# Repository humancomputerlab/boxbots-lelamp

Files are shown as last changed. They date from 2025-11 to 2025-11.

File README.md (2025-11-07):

# LeLamp

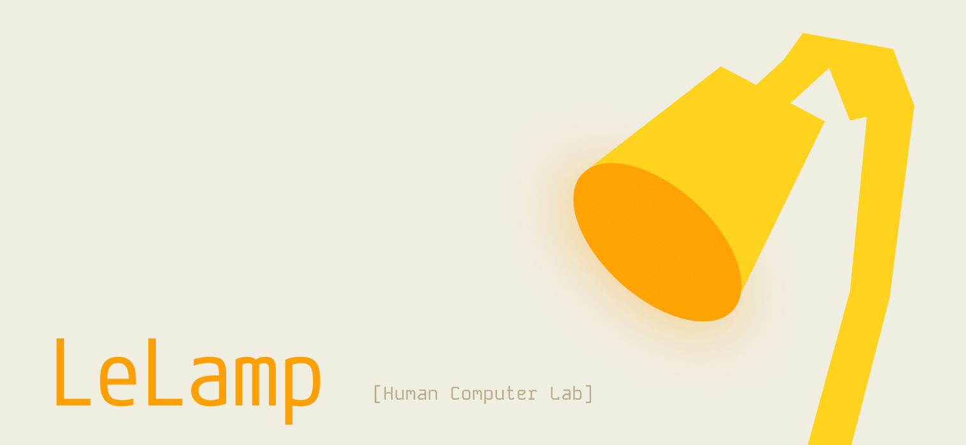
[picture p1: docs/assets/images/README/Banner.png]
LeLamp Banner


An open source robot lamp based on [Apple's Elegnt](https://machinelearning.apple.com/research/elegnt-expressive-functional-movement), made by [Human Computer Lab](https://www.humancomputerlab.com/)

## Overview

LeLamp is an expressive robot lamp featuring:

- 🎭 **5-axis articulated movement** with servo motors
- 📸 **Computer vision** via Pi Camera
- 🎤 **Audio interaction** with microphone and speaker
- 💡 **LED expressions** with 24 programmable LEDs
- 🎮 **Record & replay** custom movements

## Build Guide

**Start here:** [Prerequisites & Planning](./docs/0.%20Prerequisites.md)

### Complete Build Process

1. [📋 Prerequisites & Planning](./docs/0.%20Prerequisites.md) - Skills, tools, and BOM
2. [🔧 Components & 3D Parts](./docs/1.%203D%20Print.md) - Components and 3D Printed Models
3. [🎯 Lamp Assembly](./docs/3.%20LeLamp%20Assembly.md) - Mechanical and electrical assembly
4. [🏗️ Lamp Setup](./docs/4.%20LeLamp%20Setup.md) - Runtime Setup
5. [🎮 Lamp Control](./docs/5.%20LeLamp%20Control.md) - Controlling LeLamp
6. [🔍 Common Issues](./docs/6.%20Common%20Issues.md) - Common issues and solutions

### Quick Reference

- **Bill of Materials**: [Complete component list with suppliers](./docs/0.%20Prerequisites.md#bill-of-materials)
- **3D Print Files**: Available in `/3D/` directory ([OnShape CAD](https://cad.onshape.com/documents/16c9706360b5ad34f9c8db49/w/2edfa54c83253c120fbc9e58/e/a7196194821d9cfe2842a44a))
- **Order the Kit**: [Register interest here](https://docs.google.com/forms/d/e/1FAIpQLSfOXO2q_I2LKqYE0LoPN8VtrpKWrvJ1OkRAiS1iBFML1eqoGw/viewform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)
- **Software Control**: [LeLamp Runtime Repository](https://github.com/humancomputerlab/lelamp_runtime)

## Project Status

⚠️ **Early Development** - This project is actively being developed. We published our progress early to encourage community feedback and iteration.

## Community & Support

### Getting Help

- **Start here**: [Troubleshooting Guide](./docs/6.%20Troubleshooting.md) for common issues
- **Discord**: [Join our community](https://discord.gg/727JXBt8Zt) for real-time help and discussions
- **GitHub Issues**: [Report bugs or ask questions](https://github.com/humancomputerlab/le_lamp/issues)

### Contributing

We welcome contributions:

- 🐛 Bug reports and fixes
- 📖 Documentation improvements
- 🔧 Design enhancements
- 🌍 Regional supplier information
- 📸 Build photos and videos

Please check existing issues before creating new ones.

## Maintainers
Maintained by [Human Computer Lab](https://www.humancomputerlab.com).

## Acknowledgments & Sponsors
See [CONTRIBUTORS.md](./CONTRIBUTORS.md) for contributors and their roles.  
See [SPONSORS.md](./SPONSORS.md) for sponsor thanks and how to support the project.

## License

This project is licensed under the GNU General Public License v3.0 - see the [LICENSE](LICENSE) file for details.

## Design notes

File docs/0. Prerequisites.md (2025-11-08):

# Prerequisites for Building LeLamp

Before starting your LeLamp build, ensure you have the necessary skills, tools, and time to complete this project successfully.

## Skill Level Requirements

**Intermediate to Advanced** - This project requires:

- **Electronics experience**: Soldering, basic circuit understanding, component identification
- **3D printing knowledge**: Printer operation, material selection, post-processing
- **Software comfort**: Command line usage, SSH, basic Linux administration
- **Mechanical assembly**: Precision work with small components, heat inserts, servo mounting

**Estimated build time**: 1-2 hours (assuming prints are complete

## Required Tools

### Electronics Tools

- Soldering iron (temperature controlled, 15-25W)
- Solder (60/40 rosin core, 0.6-0.8mm)
- Wire strippers
- Small screwdrivers (Phillips #0, #1, flathead 2-3mm)
- Multimeter for continuity testing

### Mechanical Tools

- Heat insert soldering iron tip OR dedicated heat insert tool
- M2, M2.5 and M3 Allen keys/hex drivers
- Small pliers (needle nose)
- Wire cutters/flush cutters
- Digital calipers (for verification)

## Safety Warnings

⚠️ **ELECTRICAL SAFETY**

- Always disconnect power when making connections
- Use proper ESD precautions when handling Pi and servo driver
- Main power supply is 5V - verify correct voltage before connection
- Double-check polarity before powering on

⚠️ **MECHANICAL SAFETY**

- Heat inserts reach 200°C+ - use appropriate tools
- Servo horns under tension can snap - wear eye protection
- Small parts present choking hazard

**Total estimated cost (United States): $310.64 USD**

## Required External Resources

Before starting, ensure you have access to:

- **3D Printer** or printing service
- **Computer** for Pi setup and servo configuration
- **WiFi network** for Pi connectivity
- **LeLamp Runtime Repository**: https://github.com/humancomputerlab/boxbots_lelampruntime

## Time Planning

### Phase 1: Preparation (15-30 minutes)

- Download and review all documentation
- Source all components

### Phase 2: Electronics Prep (30-45 minutes)

- Test all components individually
- Solder headers and connectors
- Set up Raspberry Pi OS
- Configure servo IDs

### Phase 3: Assembly (30 min - 1 hour)

- Install heat inserts
- Mount servos in 3D printed parts
- Route wiring through body
- Assemble head components
- Final integration and testing

## Pre-Build Checklist

- [ ] All components sourced and verified working
- [ ] 3D parts printed and post-processed
- [ ] Tools and workspace prepared
- [ ] Software downloaded and accounts created
- [ ] Safety equipment ready
- [ ] Adequate time allocated (don't rush!)

## Getting Help

If you encounter issues:

- **Discord Community**: https://discord.gg/RJeRbR9sdP
- **GitHub Issues**: Report bugs and ask questions
- **Documentation**: Always check troubleshooting section first

---

**Next Step**: [1. 3D Print LeLamp](./1.%20Components%20Overview.md)

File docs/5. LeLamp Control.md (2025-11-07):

# Lamp Control

**⏱️ Estimated time:** 30 minutes  
**🔧 Required tools:** Computer with LeLamp runtime  
**📦 Required:** Fully assembled LeLamp with working head and body

For complete lamp control documentation, refer to the [**LeLamp Runtime's GitHub**](https://github.com/humancomputerlab/lelamp_runtime).

To follow this tutorial, ssh into your LeLamp and cd into `lelamp_runtime`. This was covered in the previous tutorial.

In commands below, remember to replace the name after `--id` to be your lamp name that you have used in previous section.

### Servo

Connect Pi to the servo driver through the USB port, then run the following to find which port the servo is connected to:

```bash
uv run lerobot-find-port
```

You need to unplug your USB during this process to find which port the servo is connected to. Most likely it is `/dev/ttyACM0`.

## Calibration

Before recording and replaying movements on the lamp, you need to calibrate:

```bash
sudo uv run -m lelamp.calibrate --id your_lamp_name --port your_port
```

The calibration script will run calibration twice, once for the lamp as a follower and once for the lamp as the leader. Follow the step outlined inside the CLI.

The script will mention you to put LeLamp into its zero position. The zero position is can be view in 3D [here](https://cad.onshape.com/documents/16c9706360b5ad34f9c8db49/w/2edfa54c83253c120fbc9e58/e/9bd935d578a9cbc77b5d66b3).

After putting LeLamp into its zero position, rotate each joint fully except for the lamp base motor (first motor on the base) or the lamp head motor (second motor from lamp head). **⚠️ Important: Do not fully rotate the lamp base or lamp head during calibration — this applies specifically to the two yaw servos. When setting them to their zero position, only rotate each servo about 90° clockwise and 90° counterclockwise from the center position. Rotating beyond this range may damage the servos or misalign the calibration.**

Then run the following command to check whether the servos are available and working:

```bash
uv run -m lelamp.test.test_motors --id your_lamp_name --port port_your_servo_driver_is_connected_to
```

## Record and replay movements

To record movement, run the following command in runtime:

```bash
sudo uv run -m lelamp.record --id your_lamp_name --port your_port --name rotation
```

While recording movement, you can end and save the recording by holding `CTRL + C`.

To replay movement, run the following command in runtime:

```bash
sudo uv run -m lelamp.replay --id your_lamp_name --port your_port --name rotation
```

To list all recorded movements, run the following command in runtime:

```bash
sudo uv run -m lelamp.list_recordings --id your_lamp_name
```

## Final System Testing

After completing your LeLamp build, perform these final tests:

### Full System Integration Test

```bash
# Test all servo movements
sudo uv run -m lelamp.test.test_motors --id your_lamp_name --port your_port

# Test head components
sudo uv run -m lelamp.test.test_rgb     # LED ring
uv run -m lelamp.test.test_audio        # Audio I/O
libcamera-hello --timeout 2000         # Camera
```

### Record Your First Movement

1. **Position LeLamp** in a safe working area with full range of motion
2. **Record a simple movement** to test the system
3. **Replay the movement** to verify accuracy
4. **Save successful recordings** for future use

## Congratulations! 🎉

You have successfully built your LeLamp! Your robot lamp should now be capable of:

- ✅ Expressive movement through 5 degrees of freedom
- ✅ Visual interaction via camera
- ✅ Audio input/output for voice interaction
- ✅ Programmable LED expressions
- ✅ Recording and replaying custom movements

## Next Steps

- **Explore the runtime**: Check out advanced features in the [LeLamp Runtime repository](https://github.com/humancomputerlab/lelamp_runtime)
- **Join the community**: Share your build on [Discord](https://discord.gg/4hmNW3Ep)
- **Contribute back**: Help improve documentation or share build photos
- **Report issues**: Use [GitHub Issues](https://github.com/humancomputerlab/le_lamp/issues) for bugs or suggestions

---

**Previous**: [LeLamp Setup](./4.%20LeLamp%20Setup.md) | **Troubleshooting**: [Common Issues](./6.%20Common%20Issues.md)

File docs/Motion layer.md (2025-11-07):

# Lelamp Studio

https://github.com/humancomputerlab/lelamp-studio

A web-based visual interface for animating and controlling the Lelamp robot. This React application provides a node-based graph editor to create robot animations, visualize URDF models in 3D, and export motion sequences for the robot lab.

## What It Is

The Lelamp Interface is a browser-based tool for:
- **3D Robot Visualization**: Load and view URDF robot models with interactive joint manipulation
- **Node-Based Animation Editor**: Create animation sequences using a visual graph of joint poses and transitions
- **Animation Playback**: Preview robot movements in real-time before deploying to hardware
- **CSV Export**: Generate keyframe data files compatible with robot runtime systems
- **AI-Powered Poses**: Optional integration with Neocortex AI to generate intelligent robot behaviors

## How to Use

### Setup

```bash
npm i
npm run dev
```

The application will start on `http://localhost:5173` (or your configured port).

### Basic Workflow

1. **Upload Robot Model**
   - Click "Upload Simulation" in the sidebar
   - Upload a ZIP file containing:
     - `robot.URDF` (or similar URDF file)
     - All associated mesh files (STL, DAE, etc.)
   - The robot will appear in the 3D viewer with all joints available

2. **Create Animation Sequence**
   - Use the toolbar buttons in the node graph canvas:
     - **Joint**: Create a pose node with specific joint angles
     - **Transition**: Add smooth motion between poses
     - **AI Agent**: Generate AI-powered poses (optional)
   - Click nodes to edit joint values using sliders
   - Connect nodes by dragging from output to input ports

3. **Animate and Export**
   - Click "Run Animation" to preview the sequence in the 3D viewer
   - Use "Record" to capture joint positions during playback
   - Click "Export" to download a CSV file with timestamped joint positions
   - The CSV format: `timestamp,joint1,joint2,joint3,joint4,joint5`

4. **Manual Control**
   - Select joints from the dropdown in the 3D viewer
   - Drag sliders or use the 3D manipulator to adjust joint angles
   - Changes update in real-time on the robot model

## Connecting to Robot Lab

### CSV Export Format

The exported CSV files contain keyframe data that can be consumed by the robot runtime:

```csv
timestamp,joint1,joint2,joint3,joint4,joint5
0,0.0,0.0,0.0,0.0,0.0
20,0.5,0.3,0.2,0.1,0.0
40,1.0,0.6,0.4,0.2,0.0
...
```

- **Timestamp**: Milliseconds from animation start
- **Joint values**: Radian angles for each joint (1-5 for Lelamp)

### Integration Points

1. **CSV Import/Export**: The interface can import existing CSV animations and export new ones. Use the exported CSV files with your robot runtime system.

2. **Joint State Management**: Joint values are managed via Zustand store (`src/store/useJointStore.ts`). This can be extended to send real-time commands to robot hardware via WebSocket or HTTP API.

3. **Runtime Connection** (Future): To connect directly to the robot lab:
   - Add a WebSocket client in `src/lib/robotRuntime.ts` (create this file)
   - Subscribe to joint value changes from the store
   - Send joint commands to the robot runtime endpoint
   - Implement the RGB service interface mentioned in the codebase

### Example Integration Pattern

```typescript
// Example: Send joint values to robot runtime
import { useJointStore } from '@/store/useJointStore';

const sendToRobot = (jointValues: Record<string, number>) => {
  fetch('http://robot-lab-ip:port/api/joints', {
    method: 'POST',
    body: JSON.stringify(jointValues)
  });
};

// Subscribe to joint changes
useJointStore.subscribe(
  (state) => state.jointValues,
  (jointValues) => sendToRobot(jointValues)
);
```

## Features

- ✅ URDF loader with mesh support
- ✅ Interactive 3D joint manipulation
- ✅ Node-based animation graph editor
- ✅ Smooth transition interpolation
- ✅ Animation recording and CSV export
- ✅ CSV import for existing animations
- ✅ AI-powered pose generation (Neocortex integration)
- ✅ Real-time 3D preview

## Tech Stack

- **React 18** + **TypeScript**
- **React Three Fiber** (3D rendering)
- **React Flow** (node graph editor)
- **URDF Loader** (robot model parsing)
- **Zustand** (state management)
- **Vite** (build tool)

## Project Structure

- `src/components/Viewer3D.tsx` - 3D robot visualization
- `src/components/NodeGraph.tsx` - Animation graph editor
- `src/store/useJointStore.ts` - Joint state management
- `src/lib/neocortex.ts` - AI integration (optional)

## Notes

- The interface is designed for 5-DOF robots (Lelamp), but can work with any URDF model
- Joint orientation mapping may need calibration for your specific robot
- RGB service integration is planned but not yet implemented
- See `NEOCORTEX_INTEGRATION.md` for AI features documentation

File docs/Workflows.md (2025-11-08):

# 🔄 LeLamp Workflows Guide

**🔧 Required tools:** Computer with LeLamp runtime, text editor  
**📦 Required:** LeLamp runtime repository, understanding of Python and JSON

## Overview

Workflows in the LeLamp runtime system enable you to create custom AI-powered behaviors for your robot lamp. Workflows help the robot follow a set of instructions sequentially, essentially forming a graph structure that defines how the robot should respond to different situations and execute tasks.

The LeLamp runtime uses LiveKit AI to process these workflows, allowing your robot to intelligently follow complex instruction sequences and interact with its environment. Let's deconstruct how this works.

## Workflow Structure

In the code, each workflow consists of two essential files:

1. **`workflow.json`** - Defines the workflow structure, nodes, edges, and execution logic
2. **`tools.py`** - Contains the Python functions (tools) that the workflow can call during execution

These files must be placed inside a folder named after your workflow (e.g., `my_custom_workflow/`), which you then upload to the `workflows/` folder in your LeLamp runtime repository.

## Creating a New Workflow

### Step 1: Create Your Workflow Folder

First, navigate to wherever you would like to edit the LeLamp runtime repository

```bash
cd lelamp_runtime
cd workflows
mkdir my_custom_workflow
cd my_custom_workflow
```

Replace `my_custom_workflow` with your desired workflow name. Use lowercase letters, numbers, and underscores only (e.g., `greeting_workflow`, `dance_sequence`, `morning_routine`).

### Step 2: Create `workflow.json`

Create a `workflow.json` file that defines your workflow's graph structure. This file describes:

- **Nodes**: Individual steps or decision points in your workflow, each with an `intent` that describes what the node should accomplish
- **Edges**: Connections between nodes that define the flow, supporting both normal and conditional transitions
- **State Schema**: Defines the workflow's state variables and their types
- **Preferred Actions**: Optional tools that a node can call from `tools.py`

Example `workflow.json` structure (wake up routine):

```json
{
  "id": "wake_up_workflow",
  "name": "Wake Up Routine",
  "description": "A progressive wake-up routine with LeLamp that adapts based on how the user responds",
  "author": "team",
  "createdAt": "2025-11-03T10:00:00Z",
  "state_schema": {
    "user_response_detected": { "type": "boolean", "default": false },
    "attempt_count": { "type": "integer", "default": 0 },
    "calendar_data": { "type": "object", "default": {} }
  },
  "nodes": [
    {
      "id": "wake_user_1",
      "intent": "Calmly and kindly check if the person is awake.",
      "preferred_actions": []
    },
    {
      "id": "wake_user_aggressively",
      "intent": "Shout at the user more angrily and tell them they're worthless and should get up now.",
      "preferred_actions": []
    },
    {
      "id": "get_todays_calendar_data",
      "intent": "Get the calendar data for today for the user.",
      "preferred_actions": ["get_dummy_calendar_data"]
    },
    {
      "id": "morning_message",
      "intent": "Say good morning to the user and tell them what action items they have for the day.",
      "preferred_actions": []
    }
  ],
  "edges": [
    {
      "id": "start",
      "source": "START",
      "target": "wake_user_1",
      "type": "normal"
    },
    {
      "id": "e2",
      "source": "wake_user_1",
      "target": {
        "true": "get_todays_calendar_data",
        "false": "wake_user_aggressively"
      },
      "state_key": "user_response_detected",
      "type": "condition"
    },
    {
      "id": "e4",
      "source": "wake_user_aggressively",
      "target": {
        "true": "get_todays_calendar_data",
        "false": "wake_user_aggressively"
      },
      "state_key": "user_response_detected",
      "type": "condition"
    },
    {
      "id": "e5",
      "source": "get_todays_calendar_data",
      "target": "morning_message",
      "type": "normal"
    },
    {
      "id": "e6",
      "source": "morning_message",
      "target": "END",
      "type": "normal"
    }
  ]
}
```

It might be easier to visualize it like this:

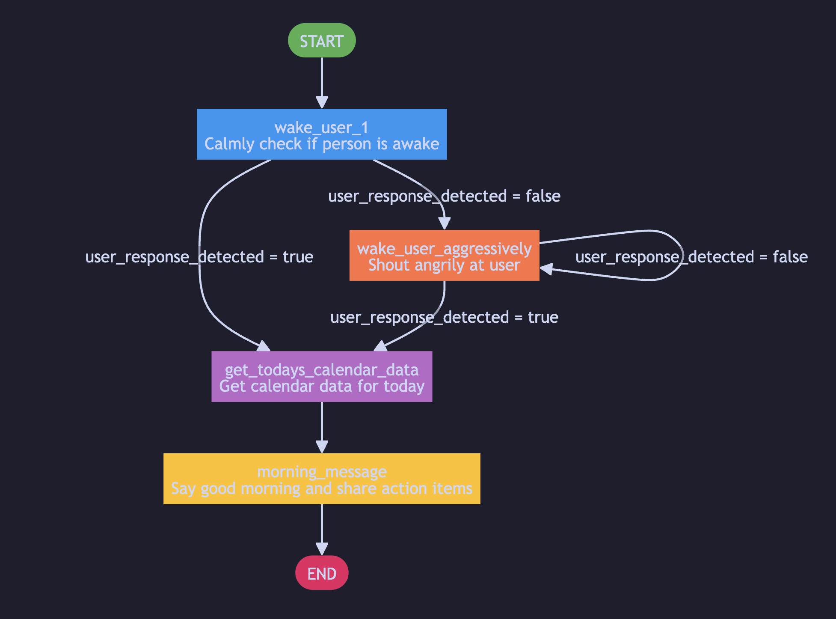
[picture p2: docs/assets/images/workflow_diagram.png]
Wake Up Routine Workflow Diagram


Notice how in some of the "nodes" we don't specify any preferred actions. This is because the AI (our Livekit agent running on OpenAI Realtime) has the ability to decide how to act on its own using its pre-existing tools that we have built (such as expressing its emotion, speaking, or changing the color of the LEDs). If you want the agent to use some more advanced/niche tools (which we highly encourage you to do), these should be defined in the `tools.py` file. .

**Key Concepts:**

- **Nodes** define intents (what should be done) rather than explicit actions, allowing the AI agent to interpret and execute flexibly
- **Edges** can be `"normal"` (direct flow) or `"condition"` (branching based on state)
- **Conditional edges** use `state_key` to check a state variable and `target` as an object with `true`/`false` paths
- **Preferred actions** are tool functions that a node should prefer to use, defined in `tools.py`. If you make custom ones and really want the AI to use it at a certain step in the workflow, you should give its name here.
- **State schema** defines variables that track workflow state across nodes.

### Step 3: Create `tools.py`

Create a `tools.py` file that implements the functions referenced in your `workflow.json`. These functions are the actual tools that your workflow can use. We created an example tool called `get_dummy_calendar_data` that looks like this:

```python
from livekit.agents import function_tool
@function_tool
async def get_dummy_calendar_data(self) -> dict:
    """
    Get the user's calendar data for today. Call this function when you need to see what
    meetings, events, or tasks the user has scheduled for the day. This helps you inform
    them about their daily schedule during the wake-up routine.

    Returns:
        A dictionary containing today's calendar events with titles, start times, and end times.
    """
    print("LeLamp: calling get_dummy_calendar_data function")
    try:
        return {
            "calendar_data": {
                "events": [
                    {
                        "title": "Meeting with John",
                        "start_time": "2025-11-04T10:00:00Z",
                        "end_time": "2025-11-04T11:00:00Z",
                    },
                    {
                        "title": "Hot Yoga Session",
                        "start_time": "2025-11-04T12:00:00Z",
                        "end_time": "2025-11-04T13:00:00Z",
                    },
                ]
            }
        }
    except Exception as e:
        result = f"Error getting dummy calendar data: {str(e)}"
        return {"error": result}
```

You could actually create a better version of this that actually connects to your real Google calendar if you want to, that would be very nice.

**Important Notes:**

- All tool functions must return something that is readable to the LLM, such as a dict, json, or just text.
- All tools must have the parameter `self`, though you can add more parameters (keep in mind that the AI fills these parameters so make sure its something that it would know).
- Use type hints for better code clarity
- Include docstrings explaining what each function does
- Import any necessary runtime modules at the top of the file

## Running Workflows

To make your workflows available when running the LeLamp agent, you need to specify them using the `WORKFLOWS` environment variable.

#### Basic Usage

Run the main workflow script with your workflows enabled:

```bash
WORKFLOWS=workflow_1 sudo uv run main_workflow.py console
```

Replace `workflow_1` with the actual names of your workflow folders (without the path, just the folder name). If you want to enable multiple workflows at once just write `WORKFLOWS=workflow_1, workflow_2" instead.

#### Example

If you have workflows named `greeting_workflow`, `dance_sequence`, and `interactive_mode`, you would run:

```bash
WORKFLOWS=greeting_workflow,dance_sequence,interactive_mode sudo uv run main_workflow.py console
```

**Note:** Ensure all workflow folder names are correct and exist in the `workflows/` directory. If a workflow name is misspelled or doesn't exist, it will be skipped (check the console output for warnings).

### Step 4: Upload Your Workflow

Once you've created both files, your workflow folder structure should look like this:

```
workflows/
└── my_custom_workflow/
    ├── workflow.json
    └── tools.py
```

If you're working on the Raspberry Pi directly, your files are already in place. If you're developing on a separate computer:

1. **Commit and push** your workflow to github
2. Pull the updates using `git pull` when ssh'd into your raspberry pi

## Workflow Best Practices

### 1. Naming Conventions

- Use descriptive, lowercase names with underscores
- Keep names concise but clear (e.g., `voice_control`, `dance_routine`, `mood_lighting`)
- Avoid special characters and spaces

### 2. Error Handling

Always include error handling in your `tools.py` functions:

```python
def my_tool(context: Dict[str, Any]) -> Dict[str, Any]:
    try:
        # Your implementation
        return {**context, "status": "success"}
    except Exception as e:
        return {**context, "status": "error", "error": str(e)}
```

### 3. State

- Remember to define the state_key within edges (such that the AI knows which state the check or update after running a node) and state_schema (such that it can define what states to keep track of from the get go).

An example of a state is `user_response_detected`. If the AI has to "check if the user is awake" at a specific node, then it will recognize this state and update it. Then when at the next edge our backend can detect that this value has been changed to eg. true and will then route the workflow in the right direction (like the diagram above).

### 5. Documentation

- Document your workflow's purpose in `workflow.json`
- Include clear docstrings in all `tools.py` functions
- Comment complex logic in your code
- Also, if your tools.py folder needs a `.env` file or something (eg. if you're connecting to an external service), then write this as a comment at the top of the tools file.

## Troubleshooting

### Workflow Not Found

If you get an error that a workflow is not found:

1. **Check the folder name** - Ensure it matches exactly (case-sensitive)
2. **Verify location** - Confirm the folder is in `lelamp_runtime/workflows/`
3. **Check file names** - Both `workflow.json` and `tools.py` must exist

### Import Errors in `tools.py`

If you encounter import errors:

1. **Check dependencies** - Ensure all imported modules are available in the runtime
2. **Verify paths** - Use relative imports or absolute imports from the runtime root
3. **Test imports** - Try importing your tools module directly:

```bash
cd lelamp_runtime
sudo uv run python -c "from workflows.my_custom_workflow.tools import greet_user"
```

### Workflow Execution Errors

If the workflow runs but fails during execution:

1. **Check console output** - Look for error messages in the terminal
2. **Validate JSON** - Ensure `workflow.json` is valid JSON (use a JSON validator)
3. **Test tools individually** - Import and test each function in `tools.py` separately
4. **Check context** - Verify that state data is being passed correctly between nodes

## Next Steps

- **Explore existing workflows** - Check the `workflows/` folder in the LeLamp runtime repository for examples
- **Share your workflows** - Contribute back to the community by sharing your workflow implementations
- **Read the runtime docs** - Refer to the [LeLamp Runtime repository](https://github.com/humancomputerlab/lelamp_runtime) for advanced features and API documentation

---

**Previous**: [LeLamp Control](./5.%20LeLamp%20Control.md) | **Troubleshooting**: [Common Issues](./6.%20Common%20Issues.md)

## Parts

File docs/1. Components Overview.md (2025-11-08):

# Components Overview

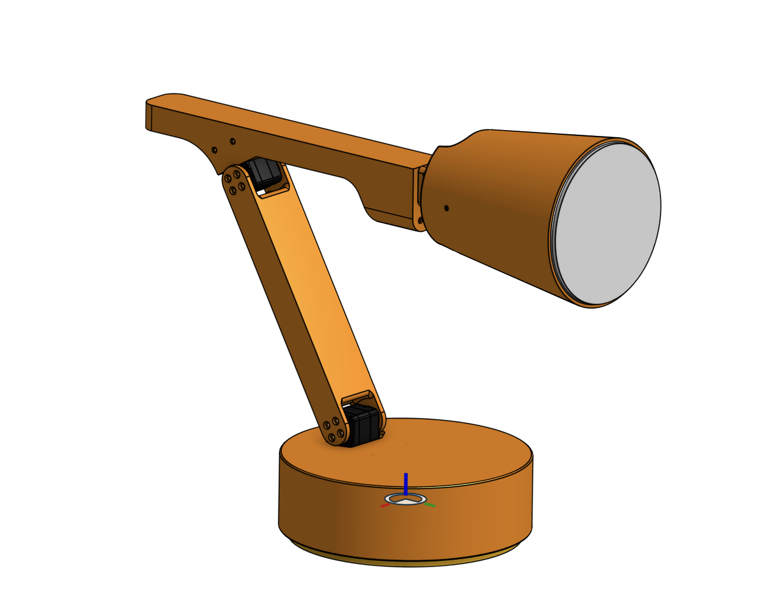
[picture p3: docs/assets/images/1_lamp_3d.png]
Lamp


## 3D Printed Parts

// Rename these parts according to the labels in the image

- **1x Lamp Base**: Contains servo driver and a normal pi.
- **1x Lamp Base Cover**: Cover lamp base.
- **1x LampArm (Base to Elbow)**: Contains base pitch and elbow pitch servo.
- **1x LampArm (Elbow to Wrist)**: Contains elbow pitch and wrist roll servo.
- **2x LampArm (Pitch)**: Contains base pitch or wrist pitch servo.
- **1x Lamp Head**: Contains led matrix and speaker.
- **1x Lamp Head - Diffuser**: Diffuse LED Matrix.

// ADD A LABELED IMAGE WITH THE PARTS

## Electronic Parts

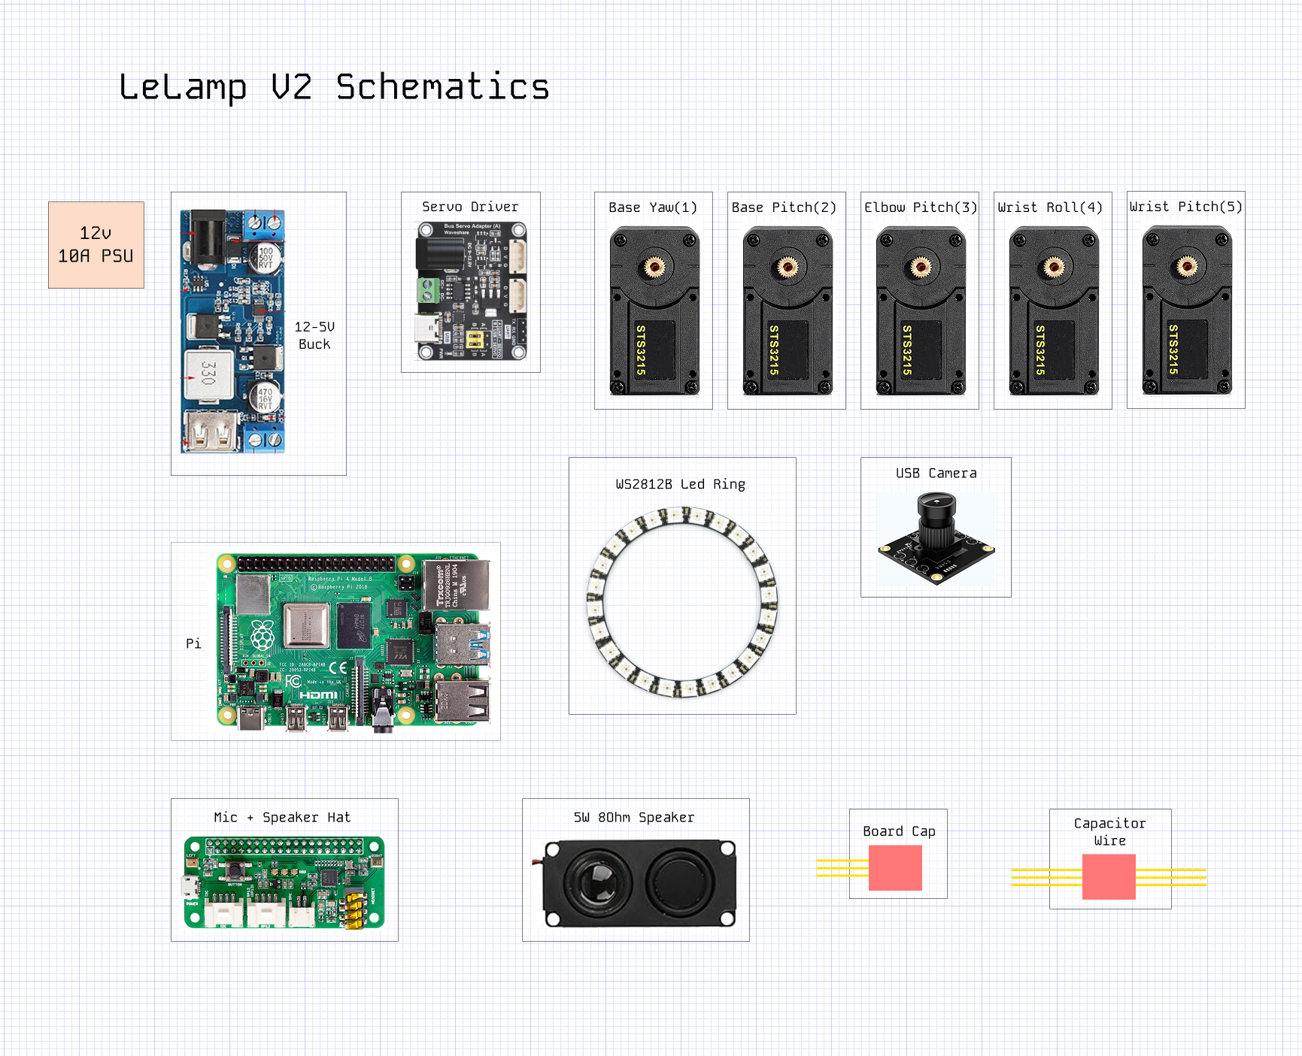
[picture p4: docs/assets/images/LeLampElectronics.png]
LeLamp Electronics


---

**Previous**: [Prerequesites](./0.%20Prerequisites.md) | **Next**: [Electronics](./2.%20Electronics.md)

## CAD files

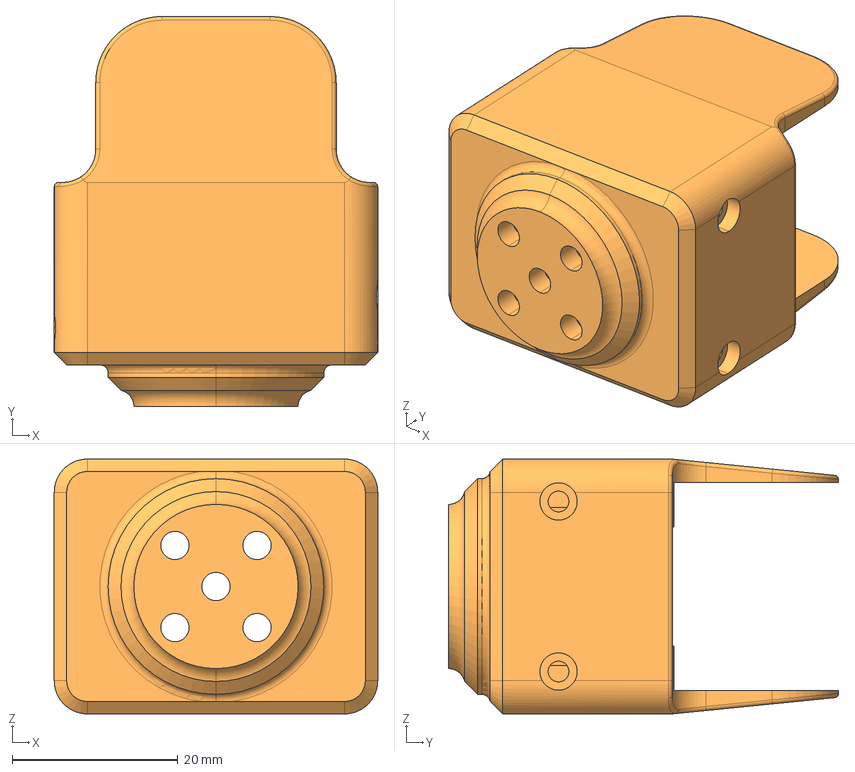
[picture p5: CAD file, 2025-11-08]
CAD/LeLamp V2 Step 3.step
39.0 x 47.0 x 30.7 mm

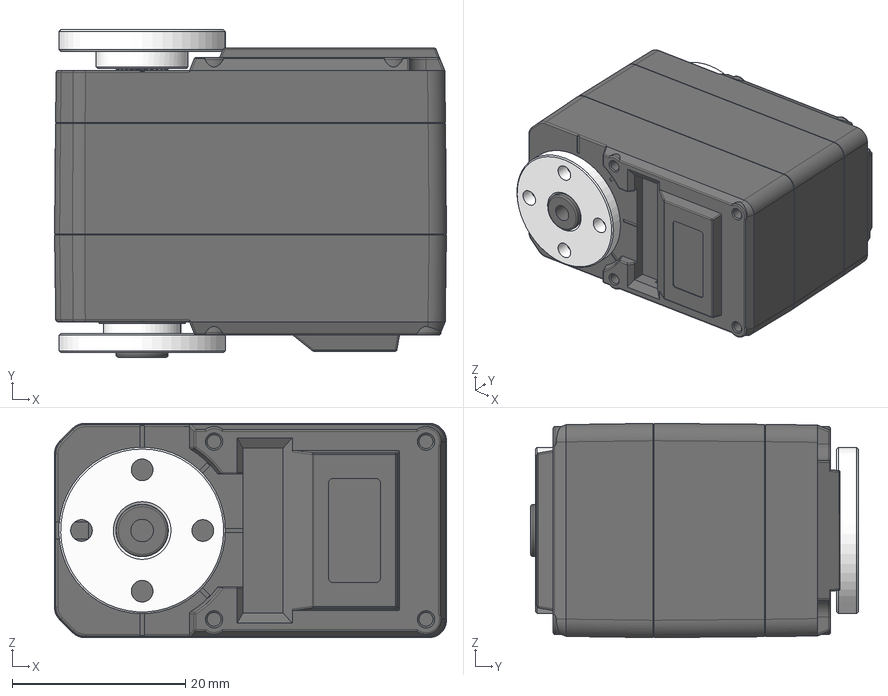
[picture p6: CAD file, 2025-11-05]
docs/assets/step/ST3215.step
45.2 x 37.8 x 24.7 mm
ZK_122
SG-ZIJI_15
XG-ZIJI_16
MOTOR-1723_3
PCB-CHAZUO_92
GE_27
金属舵盘（驱动）
金属舵盘（从动）

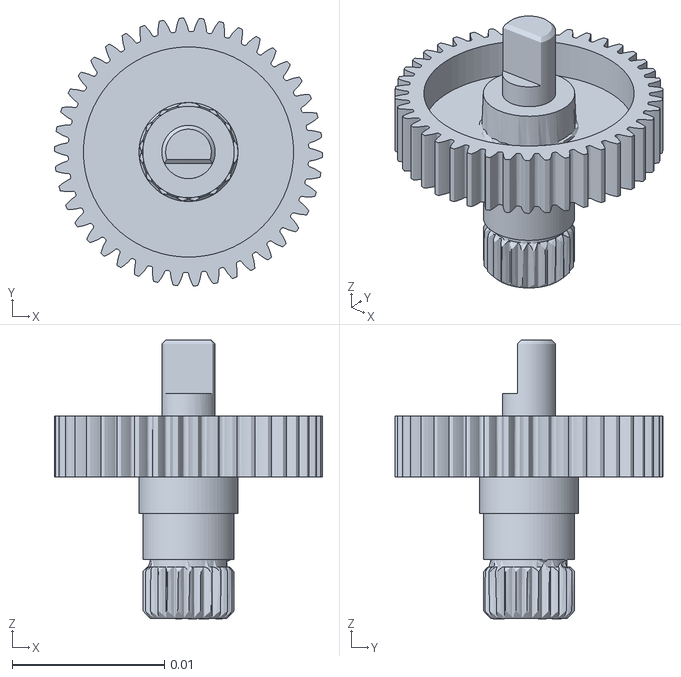
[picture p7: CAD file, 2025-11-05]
simulation/assets/ge_27.stl
0.0176 x 0.0176 x 0.0183

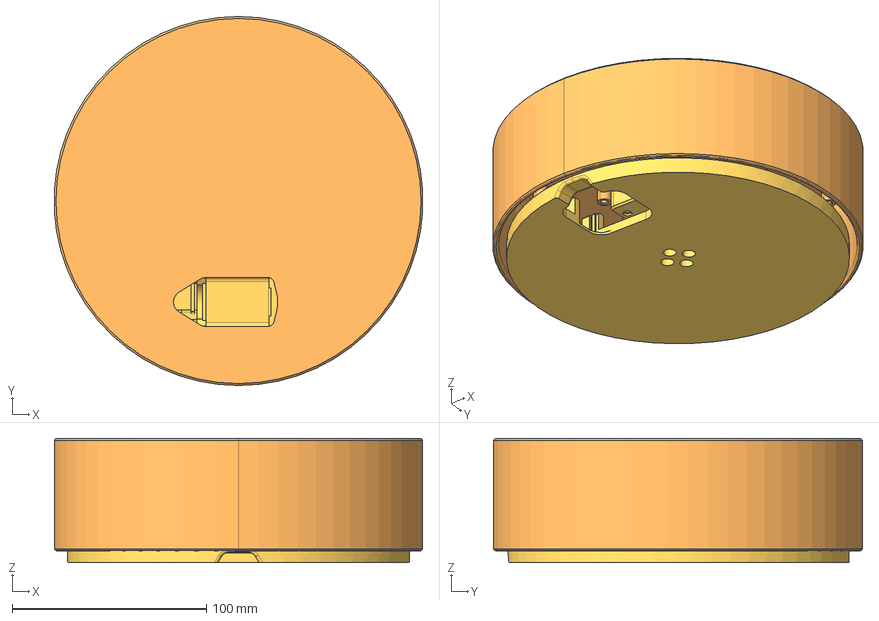
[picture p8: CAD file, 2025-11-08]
CAD/LeLamp V2 Bottom Link.step
189.7 x 190.0 x 64.0 mm

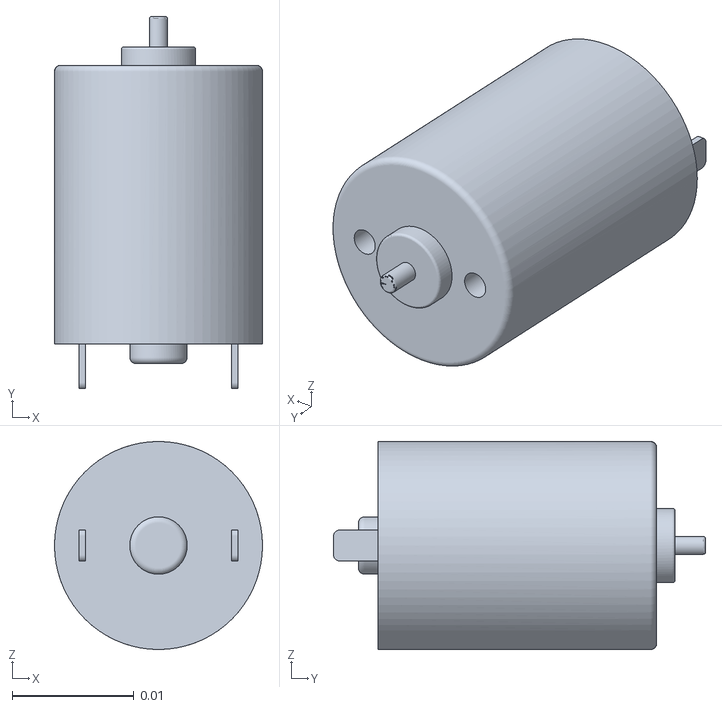
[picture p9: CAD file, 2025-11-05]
simulation/assets/motor_1723_3.stl
0.017 x 0.0305 x 0.017

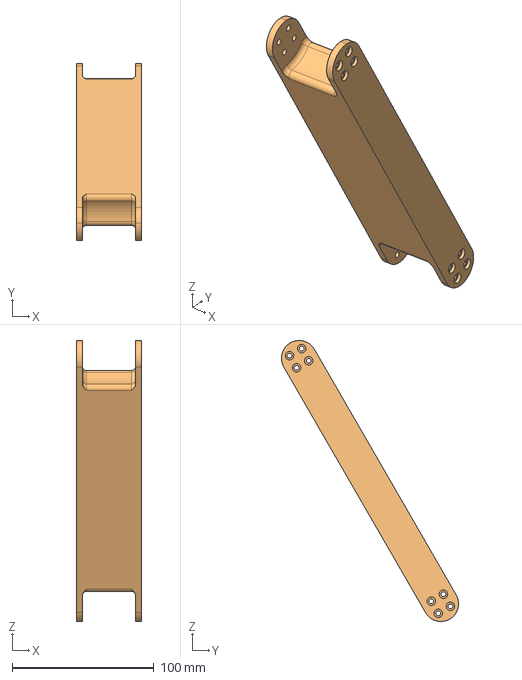
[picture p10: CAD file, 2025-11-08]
CAD/LeLamp V2 Small Link.step
45.9 x 125.0 x 198.2 mm

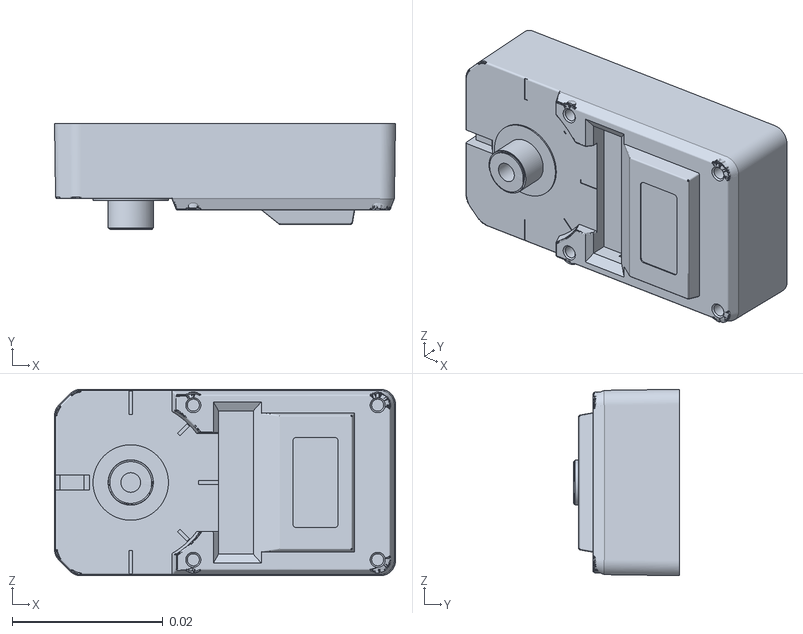
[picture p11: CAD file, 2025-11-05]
simulation/assets/xg_ziji_16.stl
0.0452 x 0.0141 x 0.0247

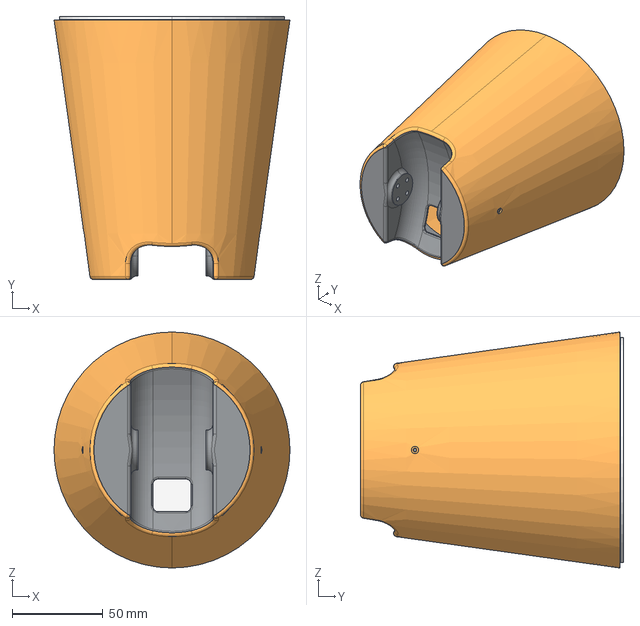
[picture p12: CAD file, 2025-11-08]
CAD/LeLamp V2 Head Parts.step
130.0 x 144.9 x 130.0 mm

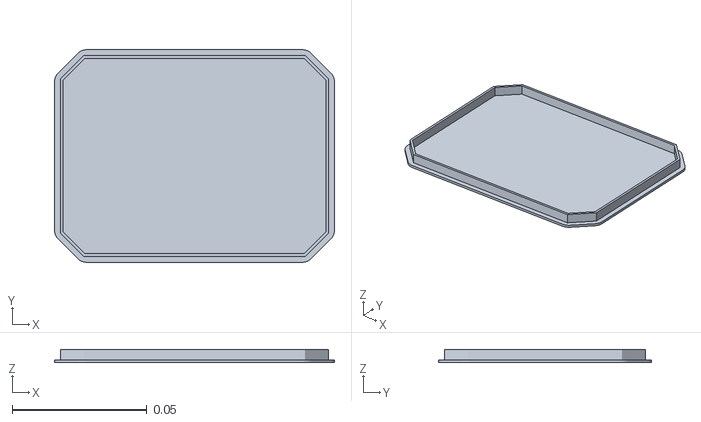
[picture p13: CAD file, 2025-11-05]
simulation/assets/diffuser.stl
0.104 x 0.079 x 0.005

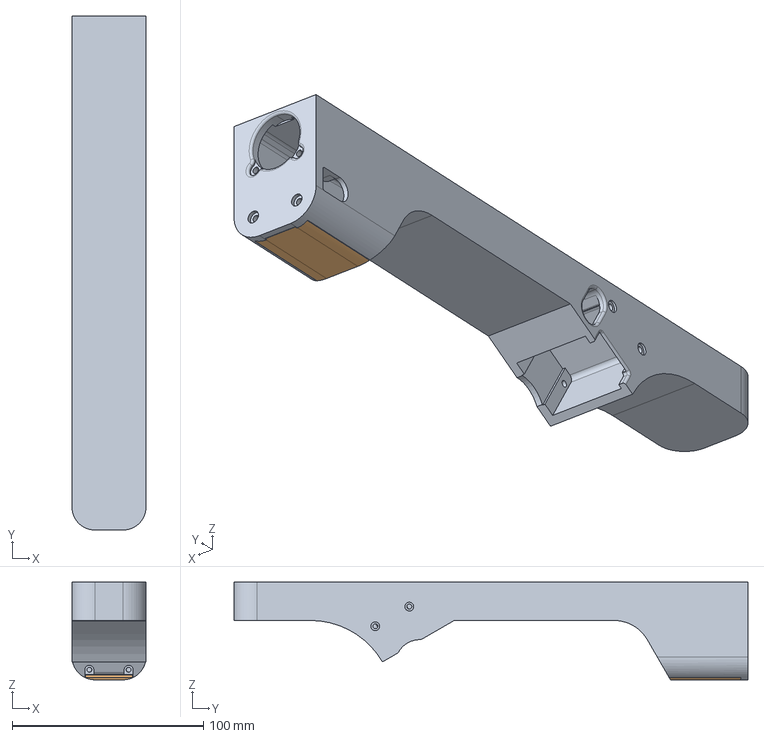
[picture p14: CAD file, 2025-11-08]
CAD/LeLamp V2 Top Link.step
38.7 x 268.4 x 51.0 mm

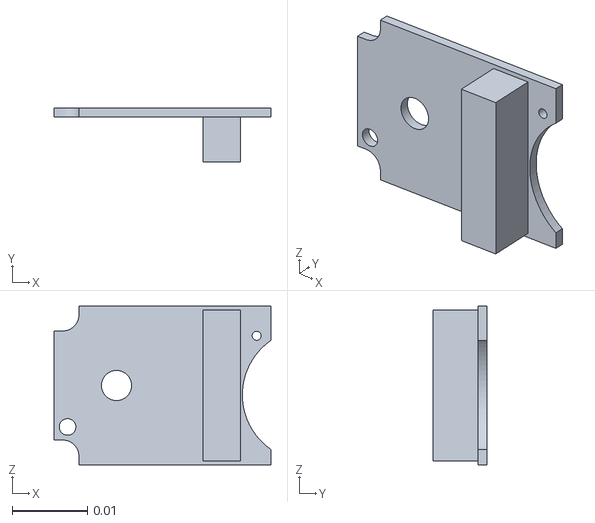
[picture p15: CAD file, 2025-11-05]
simulation/assets/pcb_chazuo_92.stl
0.0288 x 0.0072 x 0.0211

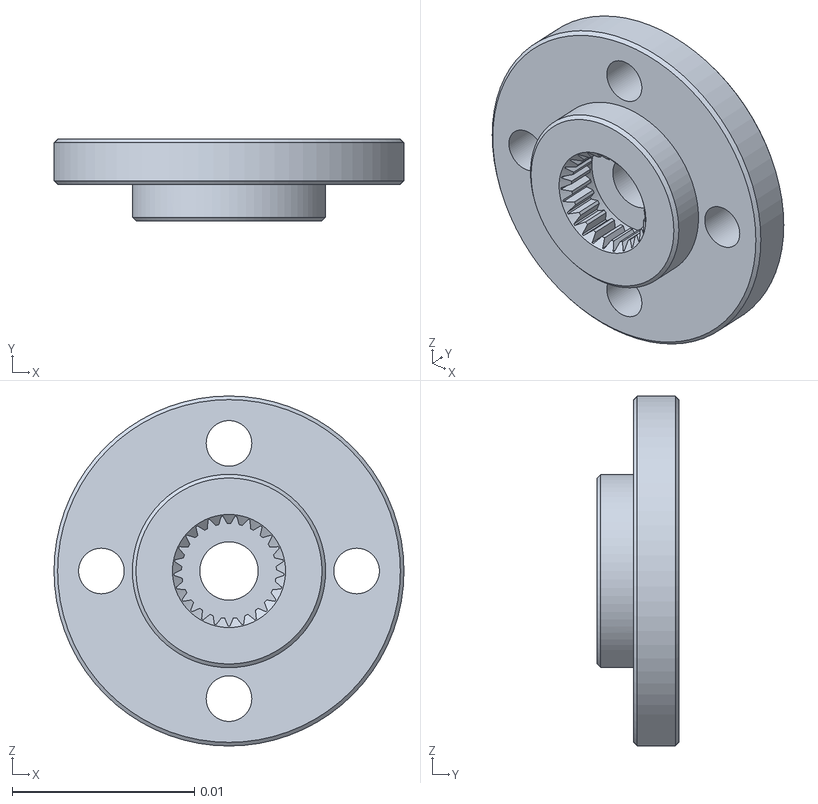
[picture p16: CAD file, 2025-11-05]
simulation/assets/金属舵盘_驱动__v2.stl
0.0192 x 0.0045 x 0.0192

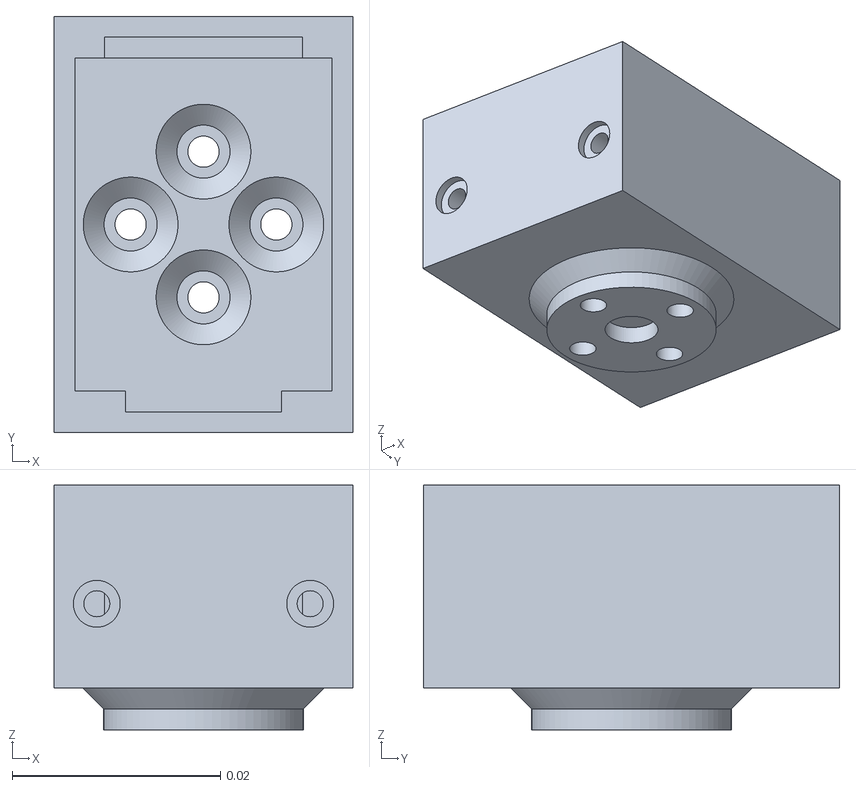
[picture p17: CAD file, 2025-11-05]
simulation/assets/lamparm__wrist_head.stl
0.0287 x 0.04 x 0.0235

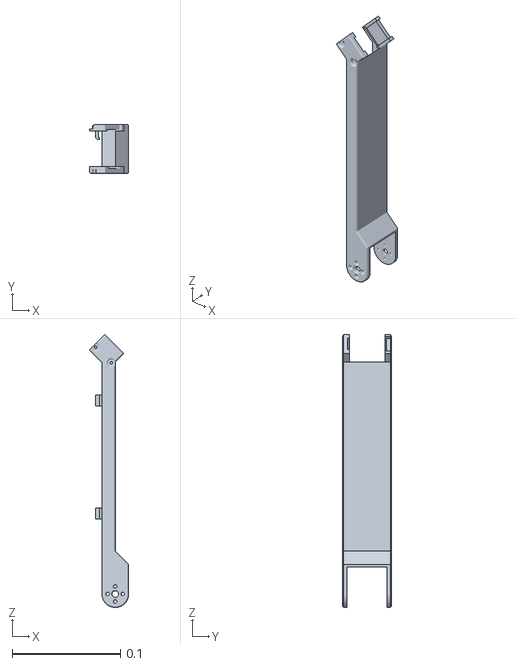
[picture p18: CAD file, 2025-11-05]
simulation/assets/lamparm__base_elbow.stl
0.0364 x 0.0452 x 0.253

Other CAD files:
simulation/assets/金属舵盘_从动__v2.stl
simulation/assets/zk_122.stl
simulation/assets/dc15_a01_led_cap2_dummy.stl
simulation/assets/arm_length_10cm.stl
simulation/assets/angle_joint.stl
simulation/assets/arm_length_15cm.stl
simulation/assets/b3b_eh.stl
simulation/assets/base.stl
simulation/assets/bts2_m2_6x8.stl
simulation/assets/dc15_a01_case_b_dummy.stl
simulation/assets/dc15_a01_case_f_dummy.stl
simulation/assets/dc15_a01_case_m_dummy.stl
simulation/assets/dc15_a01_horn_dummy.stl
simulation/assets/dc15_a01_horn_idle2_dummy.stl
simulation/assets/dc15_a01_idle_cap_dummy.stl
simulation/assets/lamp_base.stl
simulation/assets/lamp_base_cover.stl
simulation/assets/lamp_head.stl
simulation/assets/lamparm__elbow_wrist.stl
simulation/assets/lamphead.stl
simulation/assets/sg_ziji_15.stl
simulation/assets/square_joint.stl

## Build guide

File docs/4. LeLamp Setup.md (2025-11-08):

# 🛠️ LeLamp Runtime Setup Guide

**⏱️ Estimated time:** 1–2 hours
**🔧 Required tools:** Computer, USB cable, SD Card Reader
**📦 Required components:** Raspberry Pi, SD Card

## 1. OS

Using [Pi Imager](https://www.raspberrypi.com/software/), flash **Raspberry Pi OS Lite (64-bit)** onto your Raspberry Pi. You can reference how to do this [here](httpss://www.raspberrypi.com/documentation/computers/getting-started.html).

In this tutorial, we used the Debian Bookworm version (released 2025-05-13).

When prompted to configure the settings on your pi, remember to:

Make sure to use your mobile hotspot only.

- Set the Wifi SSID and password.
- Set the username and password.
- Set the hostname
- Enable SSH

## 2. Runtime

**Important Note:** As a common practice, review the output of each command carefully after running. Do as you are instructed within each command and their output.

After successfully flashing your pi, SSH into it by running the following command:

```bash
ssh your_username@your_host_name.local
```

Then you need to set up [LeLamp Runtime](https://github.com/humancomputerlab/boxbots_lelampruntime):

```bash
git clone https://github.com/humancomputerlab/boxbots_lelampruntime.git
```

To use LeLamp's runtime, install uv:

```bash
curl -LsSf https://astral.sh/uv/install.sh | sh
```

Install the necessary dependencies for audio:

```bash
sudo apt-get install portaudio19-dev
```

To setup the runtime:

```bash
cd boxbots_lelampruntime
uv sync --extra hardware
```

This will take a while. If uv is not recognized you will have to restart the terminal.

## 3. Setup Mic and Speaker

If you use the ReSpeaker Hat for Raspberry Pi, you can reference their tutorial [here](https://wiki.seeedstudio.com/respeaker_2_mics_pi_hat_raspberry_v2/).

For convenience, the tutorial is below:

1. Get Device Tree Source (DTS) for the ReSpeaker 2-Mics Pi HAT (V2.0), compile it and install the device tree overlay.

   ```bash
   curl https://raw.githubusercontent.com/Seeed-Studio/seeed-linux-dtoverlays/refs/heads/master/overlays/rpi/respeaker-2mic-v2_0-overlay.dts -o respeaker-2mic-v2_0-overlay.dts
   dtc -I dts respeaker-2mic-v2_0-overlay.dts -o respeaker-2mic-v2_0-overlay.dtbo
   sudo dtoverlay respeaker-2mic-v2_0-overlay.dtbo
   sudo cp respeaker-2mic-v2_0-overlay.dtbo /boot/firmware/overlays
   ```

2. Edit /boot/firmware/config.txt:

   ```bash
   sudo tee -a /boot/firmware/config.txt >/dev/null <<'EOF'
   dtoverlay=respeaker-2mic-v2_0-overlay
   dtoverlay=i2s-mmap
   EOF
   ```

3. Edit sudo's sound config:

```bash
sudo tee /etc/asound.conf > /dev/null <<'EOF'
# Default capture & playback device = Seeed 2-Mic
pcm.!default {
    type plug
    slave {
        pcm "hw:3,0"      # input/output device (Seeed 2-Mic)
    }
}

ctl.!default {
    type hw
    card 3
}
EOF
```

4. Reboot your device:

   ```bash
   sudo reboot
   ```

5. Check if your device is enabled:

   ```bash
   aplay -l
   ```

   The expected output should be like this:

   ```bash
   card 2: seeed2micvoicec [seeed2micvoicec], device 0: 1f000a4000.i2s-tlv320aic3x-hifi tlv320aic3x-hifi-0 [1f000a4000.i2s-tlv320aic3x-hifi tlv320aic3x-hifi-0]
   Subdevices: 1/1
   Subdevice #0: subdevice #0
   ```

   Afterwards, you can set up the sound level with the following command:

   ```bash
   alsamixer
   ```

   Inside alsamixer, you can F6 to select device `seeed2micvoicec`. The audio setting to be edited is `Line`, `Line DAC`, `PCM`. This audio setting can be muted by default, which you can unmute by typing `M` when selecting `Line`. You should set the volume level to 100 on the first try.

   **Note:** The alsamixer interface requires a full terminal emulator and may not work properly in IDE integrated terminals.

## 4. Test functionalities

### RGB

For RGB, run the following command with sudo:

```bash
sudo uv run -m lelamp.test.test_rgb
```

In case you can't find uv as root, run:

```bash
which uv
```

Then replace uv with the output, for example:

```bash
sudo /home/pi/.local/bin/uv run -m lelamp.test.test_rgb
```

If you don't want to do this long path every single time, you can add the path to uv to sudo's secure path:

```bash
sudo visudo
```

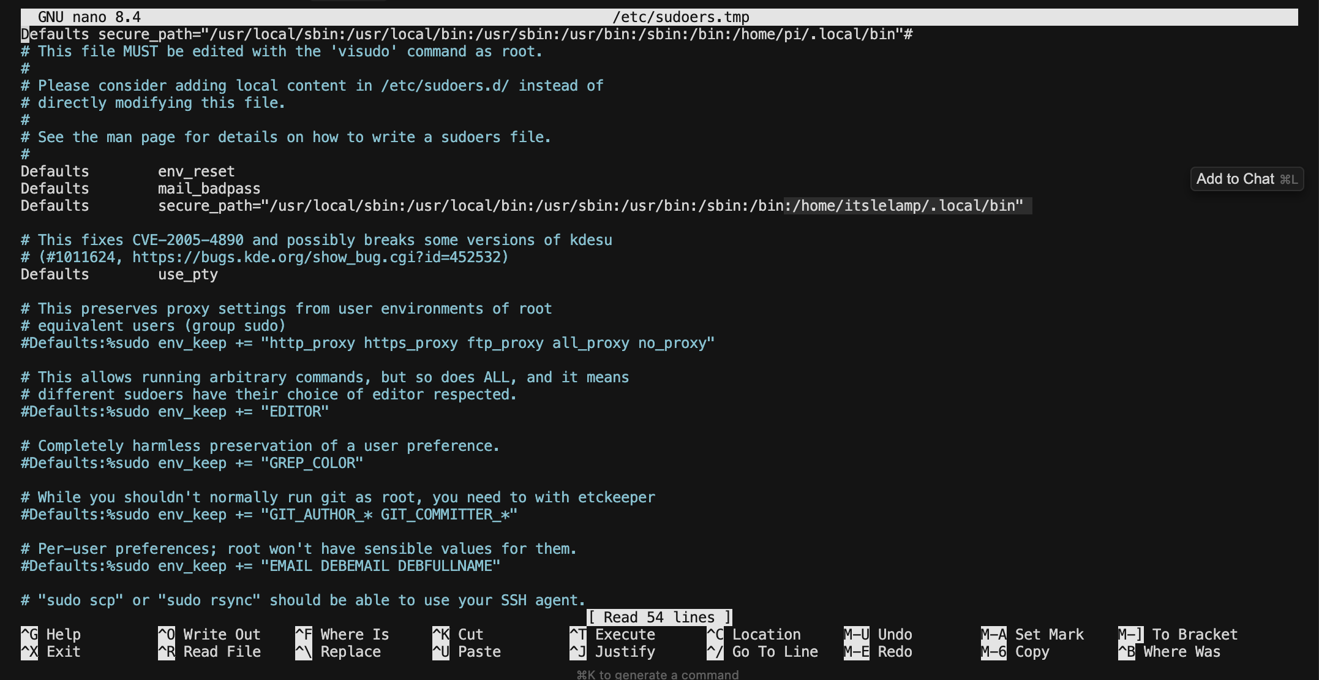
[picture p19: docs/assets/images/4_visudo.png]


Add the following `/home/pi/.local/bin` (Remember to change your username):

```bash
Defaults secure_path="/usr/local/sbin:/usr/local/bin:/usr/sbin:/usr/bin:/sbin:/bin:/home/<your_user_name_here>/.local/bin"
```

### Mic and Speaker

For Mic and Speaker, run the following command:

```bash
uv run -m lelamp.test.test_audio
```

You should hear a beep, audio will be recorded and then replayed.

## Assembly Completion Checklist

After completing lamp setup, verify:

- Working Audio input and output
- Functional LEDs

## What You Should Have

At this stage, you should have:

- **A functional LeLamp**.

---

**Previous**: [LeLamp Assembly](./3.%20LeLamp%20Assembly.md) | **Next**: [LeLamp Control](./5.%20LeLamp%20Control.md)

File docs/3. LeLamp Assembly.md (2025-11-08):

# 🛠️ LeLamp Assembly Guide

**⏱️ Estimated time:** 1–2 hours
**🔧 Required tools:** Soldering iron, screwdrivers, heat insert tool  
**📦 Required components:** Raspberry Pi, ReSpeaker Hat, speaker, LED Matrix, SD card, servo driver

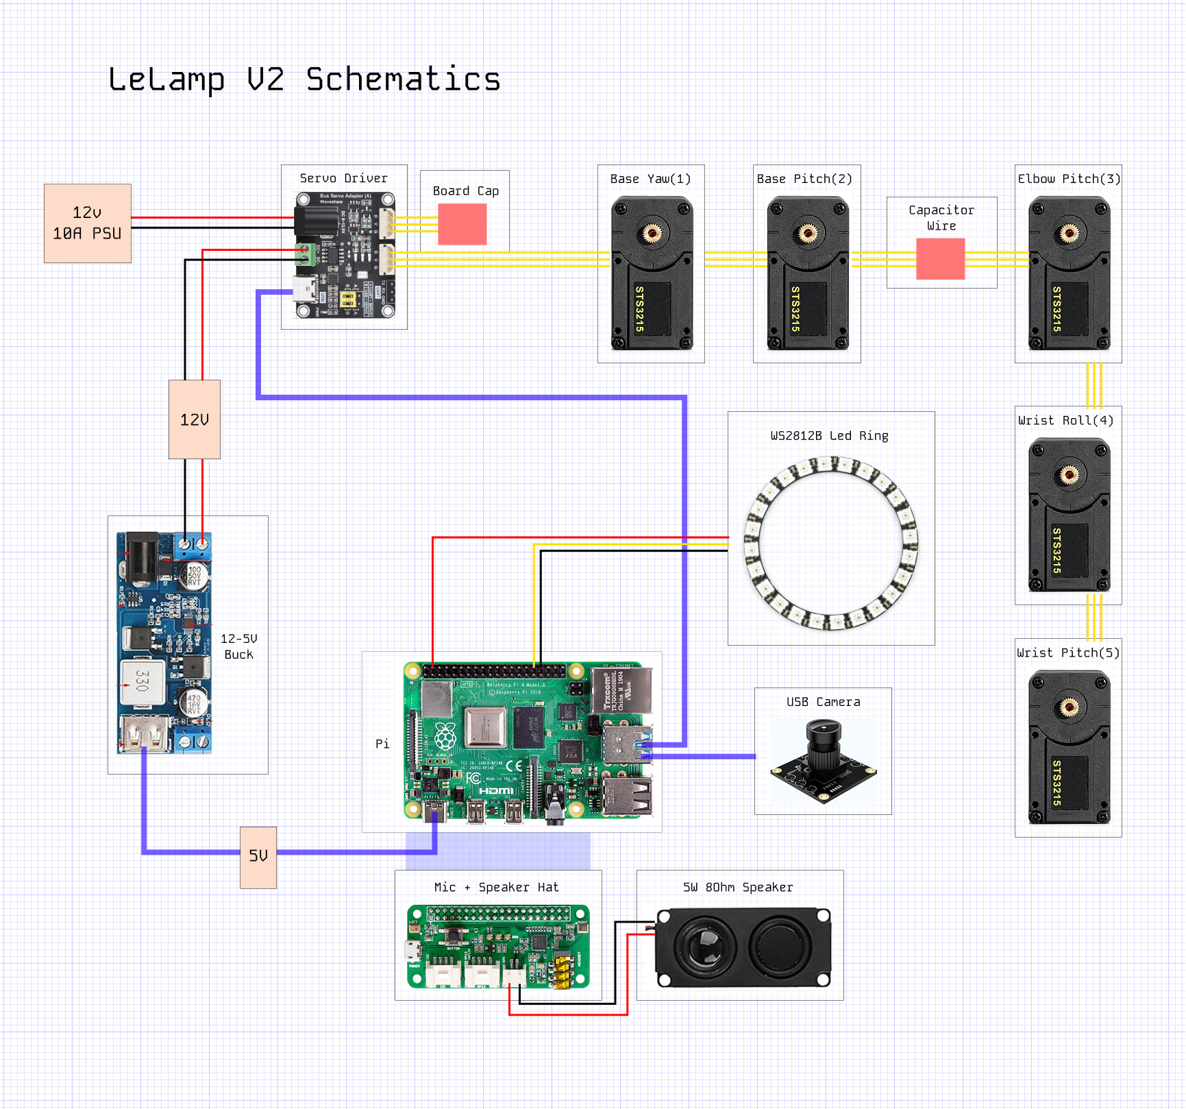
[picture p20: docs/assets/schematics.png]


## Overview

LeLamp consists of three main sections: the **Head**, the **Base**, and the **Body**, each containing essential functional components.

### LeLamp Head

- **LED Matrix** — WS2812B programmable LEDs for expression

### LeLamp Base

- **Raspberry Pi with ReSpeaker Hat** — Controls servos, audio, and LEDs
- **Motor Driver** — Drives the servo motors

### LeLamp Body

- **Motors** - Actuators of the Lamp
- **Speaker** — 4 Ω / 3 W audio output

There will be a power, data and ground cable routed all the way to the head for the LEDs, along with a usb cable for the camera.

## Soldering and Assembly

### 1. Assembling the LeLamp Base

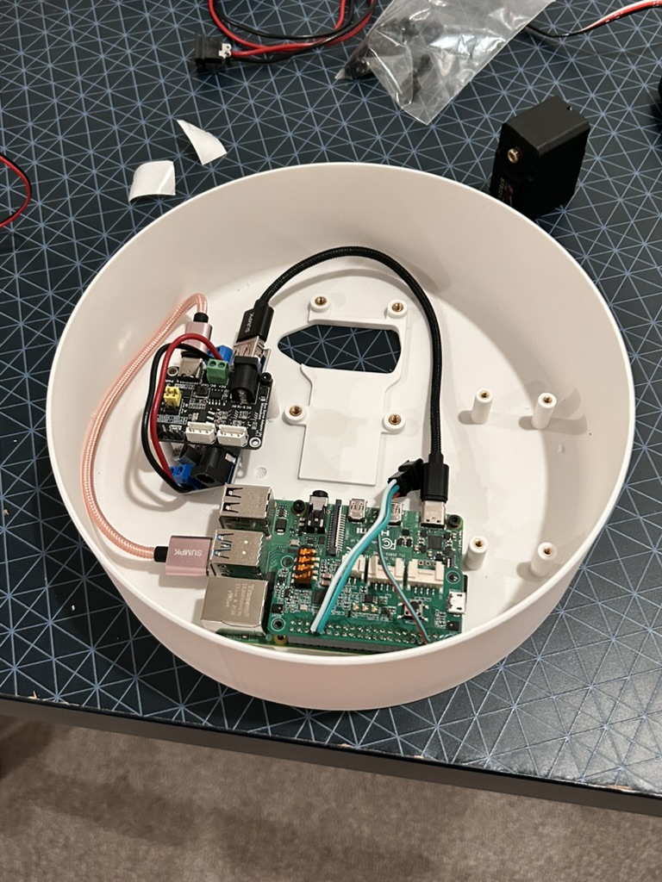
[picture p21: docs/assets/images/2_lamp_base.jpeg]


1. **Place inserts on electronics mounts**
   - Put down M2.5 heatset inserts on the **tall** electronics mounts
   - Put down M3 heatset inserts where the servos are mounted (the **short** mounts in the middle)
1. **Mount the electronics:**
   - Secure the **motor driver board** and **Raspberry Pi** inside the base as shown above with M2.5 screws (8mm).
   - Fit the **12V-5V stepdown board** snugly underneath the motor driver board (no mounts for this one, sorry)
   - The last **tall** mounts can be used for the speaker
   - The **short** mounts is for the base core (which contains two motors)
1. **Connect the boards:**

   - Use a **USB Type-C cable** to connect the motor driver to the Raspberry Pi (see image above)
   - Connect the stepdown board with a **USB Type-C cable** to the Raspberry Pi (see image above)
   - Connect the stepdown board from the screw terminal (next to the barrel connector) to the motor driver board's green screw terminal
     Look for the +/- signs on the screw terminals to determine the positive and negative connections (positive to positive, negative to negative)

1. **Prepare the ReSpeaker Hat:**

   - Solder the **header pins** on the ReSpeaker Hat as shown in the image.

   

1. **Connect the ReSpeaker Hat as shown in below image**
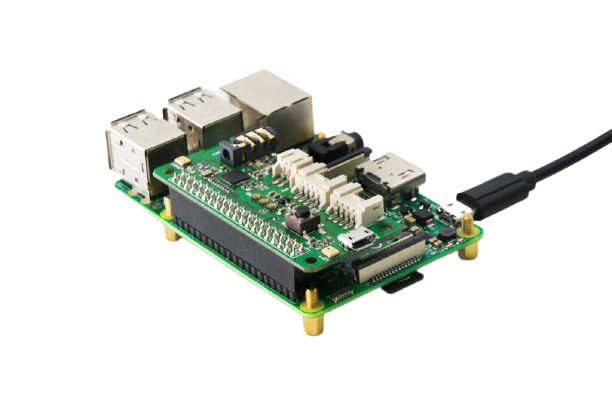
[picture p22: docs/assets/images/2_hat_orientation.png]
   

1. **Assemble the base core**

   (a) Put in the Base Pitch Actuator (ID-2) from the top and fasten it down with M2 screws

   (b) Plug in both wires that go into the Base Yaw actuator (ID-1) and route one of the wires through the hole on the side. Then push the Base Yaw actuator (ID-1) into the slot while pulling the routed cable taut and holding the other cable flat against the body of the actuator. You have to remove the rotor plate for this.

   (c) Connect the routed wire to the base pitch actuator (ID-2)

   <table>
   <tr>
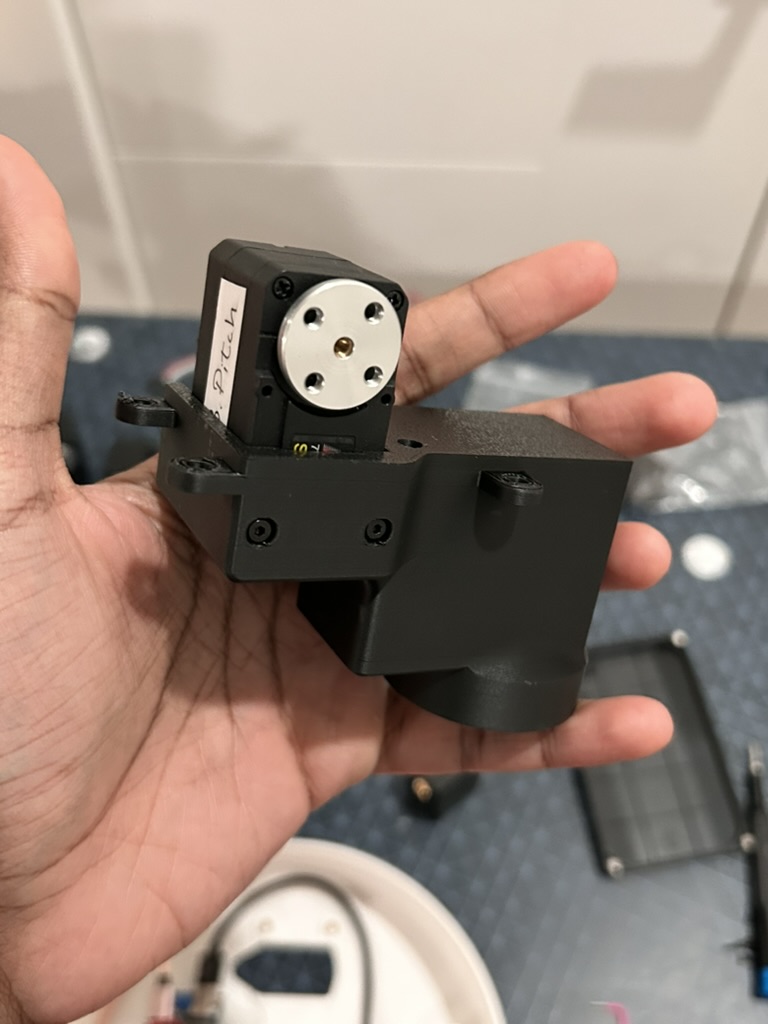
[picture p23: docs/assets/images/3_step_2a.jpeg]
Step 2a
   <td></td>
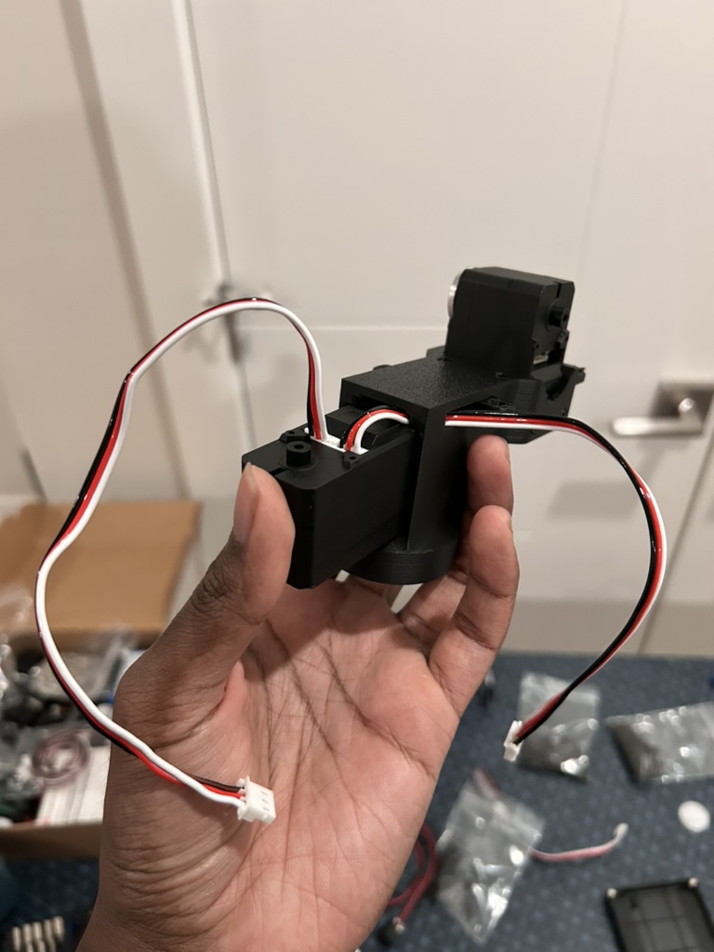
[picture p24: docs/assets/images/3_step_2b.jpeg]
Step 2b
   <td></td>
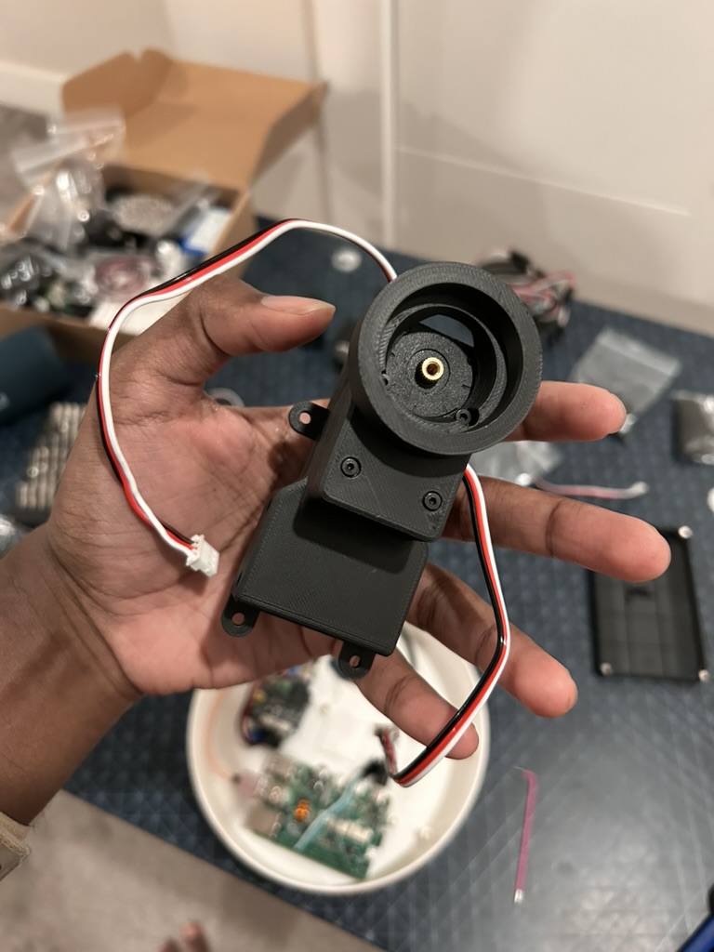
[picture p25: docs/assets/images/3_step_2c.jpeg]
Step 2c
   <td></td>
   </tr>
   </table>

1. **Completing the base**

   - Fasten down the core you just assembled into the M3 heatset inserts on the base cover using M3 screws.
   - Tidy up the wiring and make sure it's not too loose
   - Take the panel mount barrel jack and attach it to the bottom base plate, then hold down any extra loop wire with tape. Make sure to have enough slack so that the base is still able to rotate.
   - If you don't have the panel mount socket soldered to a barrel jack wire, do that.

   <table>
   <tr>
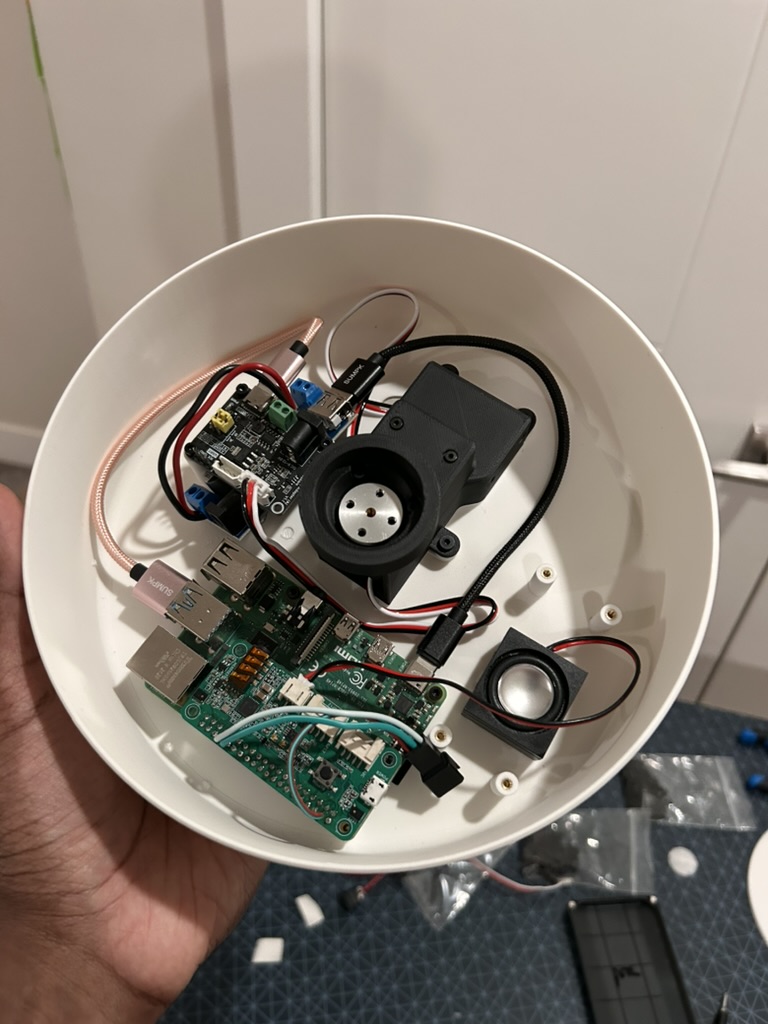
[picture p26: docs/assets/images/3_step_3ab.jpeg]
Step 3ab
   <td></td>
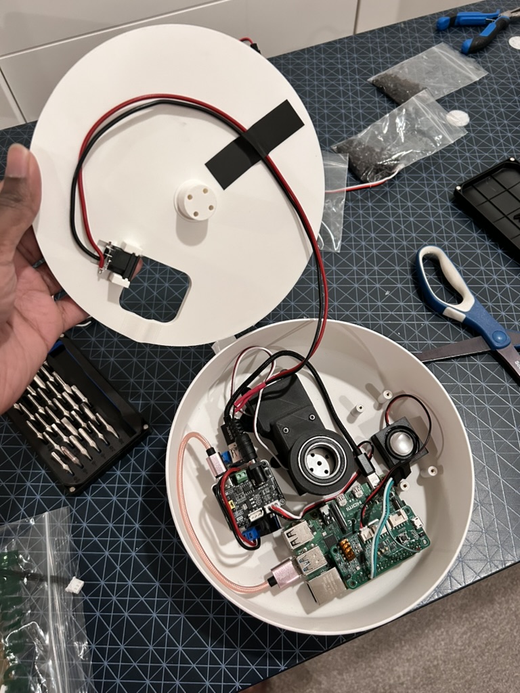
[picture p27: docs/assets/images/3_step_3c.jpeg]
Step 3c
   <td></td>
   </tr>
   </table>

1. **Connect the head wiring:**
   - connect jumper wires to the LED wires coming from the base. These wires will be plugging into the ports on the LED array

> ⚠️ _Reminder:_ Double-check all connections before powering on. Incorrect wiring can damage components.

### 2. Assembling LeLamp Body

You can find the 3D model of the robot in [OnShape](https://cad.onshape.com/documents/9550bfca8afe239c9c77175c/w/ef96633be1293d7199c6c822/e/2d4b5fbfb0593cc7c52def2b).

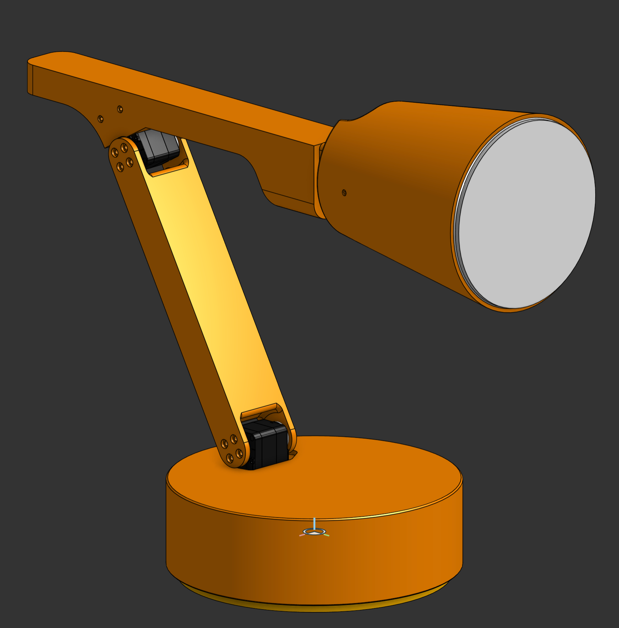
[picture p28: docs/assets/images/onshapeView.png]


> NOTE: If you will use the LED at the head, remember to route the 3 LED wires together with the motor wires throughout the cabe routes in the lamp's body. This is not shown in the images below.

#### Assembling Link 1

a. Plug the wire for link 1 into the Base Pitch actuator (ID-2)

b. Fasten link 1 to both rotor plates of Base Pitch actuator (ID-2).

c. Route the wire (and the LED wire) through the channel and place the cover on top.

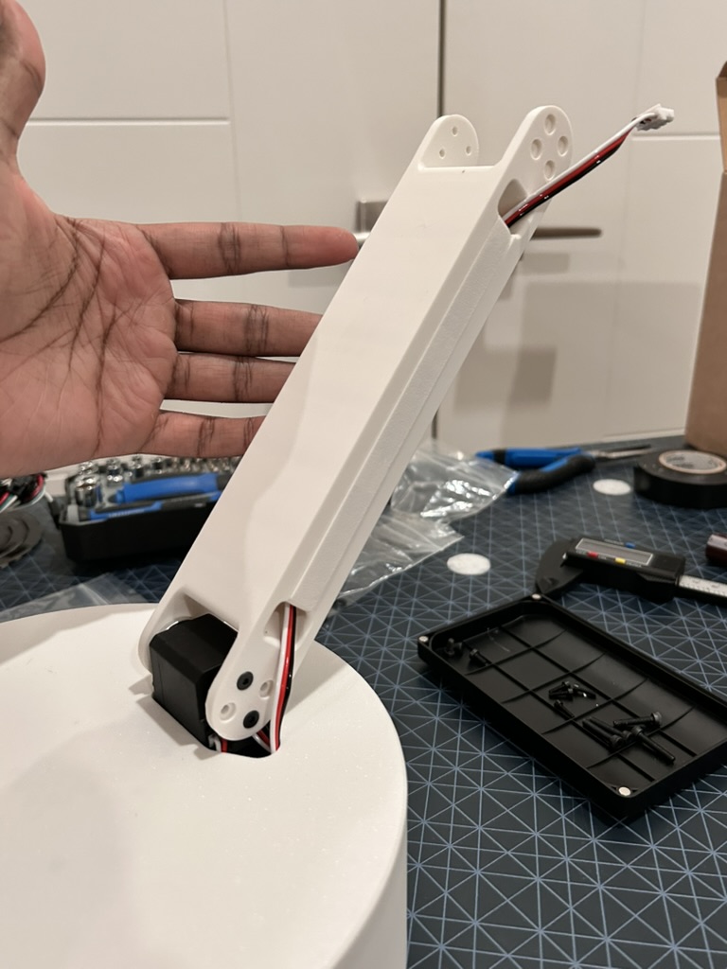
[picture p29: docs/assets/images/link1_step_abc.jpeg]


#### Assembling Link 2

a. Plug both wires into the Wrist Roll actuator (ID-4). Then take the long wire (+ the LED wire) and put it through the channel down link 2 and grab it from the other end. Route the shorter wire through the opening at the end of the link.

   <table>
   <tr>
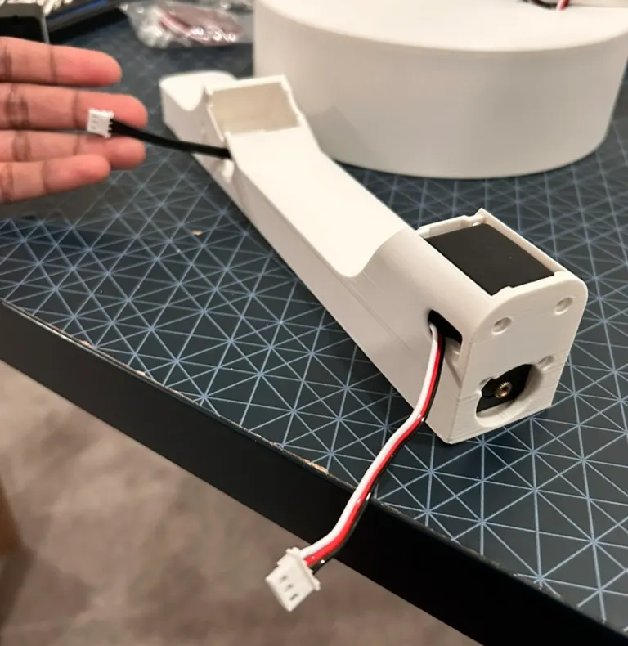
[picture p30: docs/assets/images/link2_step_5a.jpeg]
Step 5a
   <td></td>
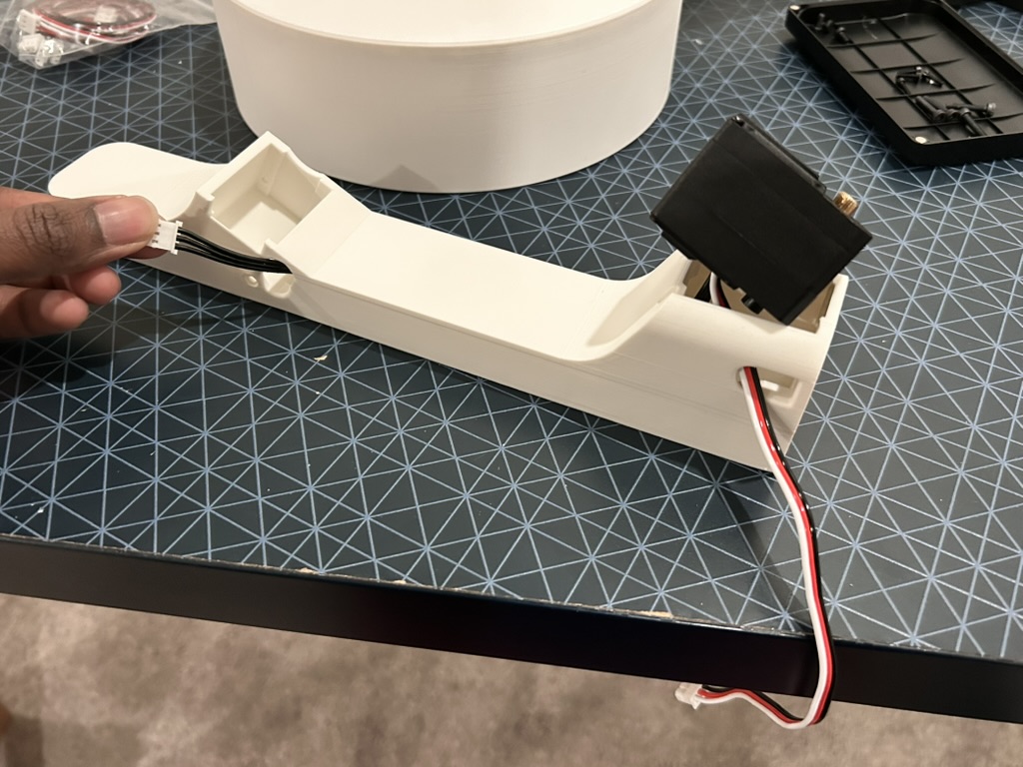
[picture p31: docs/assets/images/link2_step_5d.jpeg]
Step 5d
   <td></td>
   </tr>
   </table>

b. You have to remove the rotor plate for this. Push the actuator in while pinning down the short wire in the channel designed for it.

   <table>
   <tr>
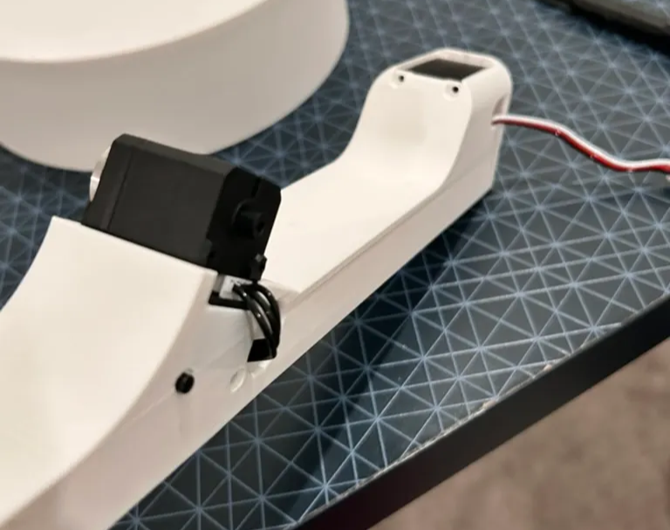
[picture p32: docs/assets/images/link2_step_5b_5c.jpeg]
Step 5b, c
   <td></td>
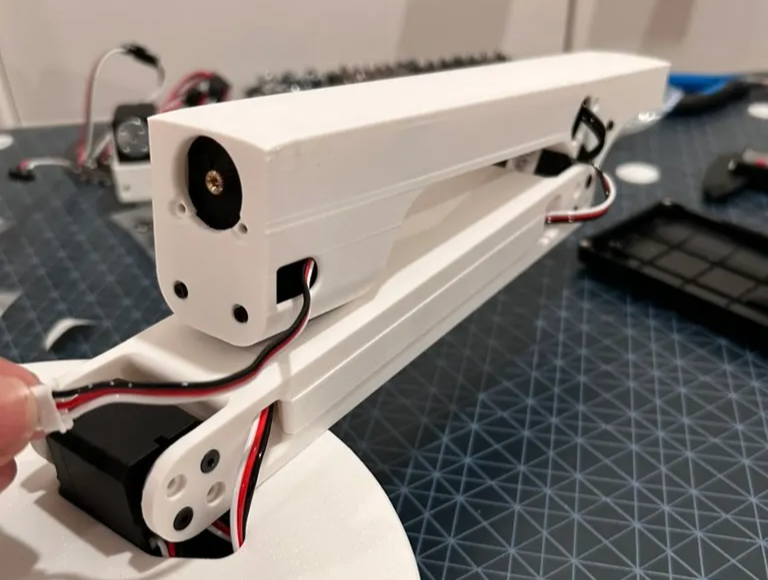
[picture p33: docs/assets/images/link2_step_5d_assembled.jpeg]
Step 5d
   <td></td>
   </tr>
   </table>

c. Once it is snugly in place, and the wire lengths are appropriate you can fasten it down with the M2 screws

d. Then you can slot in the elbow pitch actuator (ID-3), connect the wire to the closer socket and fasten it down.

e. Finally attach the second link to the first at the elbow pitch rotor plate.

#### Assembling Link 3

a. Put on the rotor plate on the wrist roll actuator. Screw into the central hole (to ensure the rotor plate is fixed in place). Then fasten down the 3rd link.

b. Put in the Wrist Pitch actuator (ID-5), wire it up and fasten it to the link.

   <table>
   <tr>
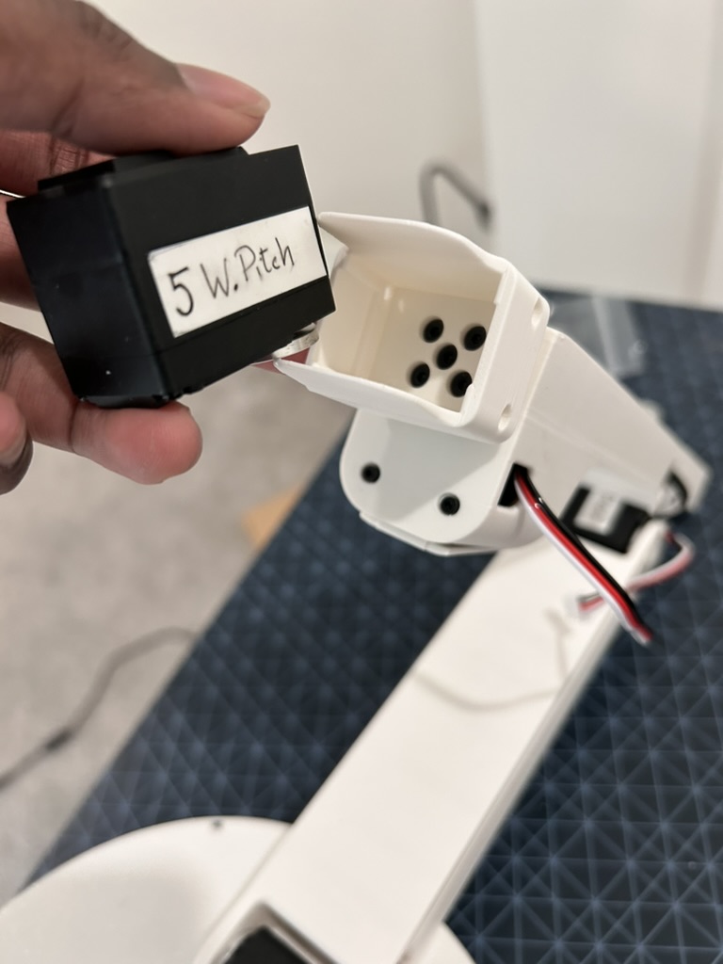
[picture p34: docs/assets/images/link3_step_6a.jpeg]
Step 6a
   <td></td>
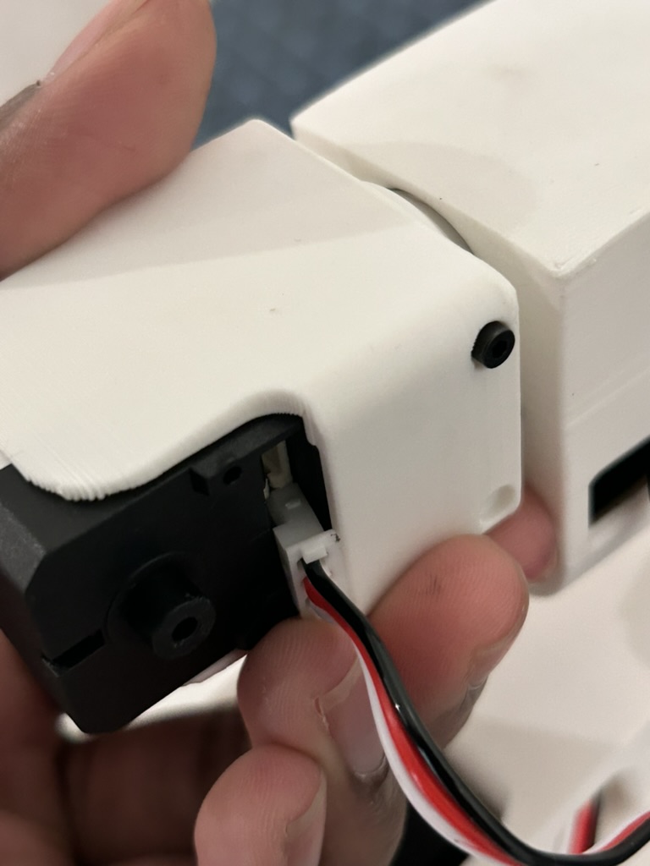
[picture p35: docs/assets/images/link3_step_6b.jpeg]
Step 6b
   <td></td>
   </tr>
   </table>

## Motor Assembly

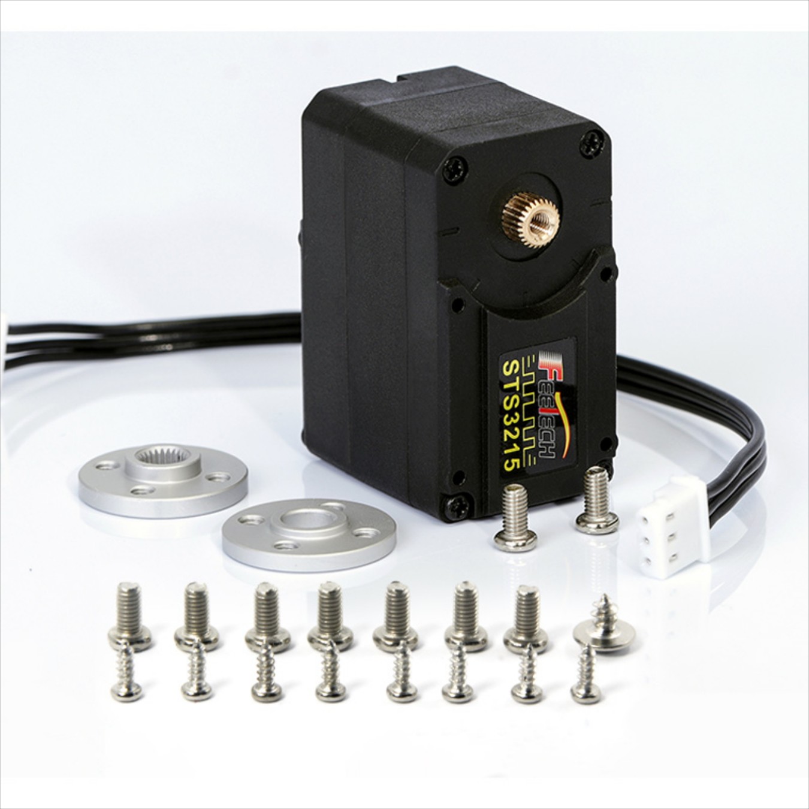
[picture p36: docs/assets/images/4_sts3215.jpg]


Each STS3215 servo motor comes with two motor horns — one with gears and one without. Before mounting the servos onto the lamp structure, first attach the geared horn to the motor’s output side (the side with the copper gear) and secure it firmly with screws. On the opposite side, place the non-geared horn; this one does not need to be screwed in, as it serves only for axis alignment.

Because the motor body is asymmetrical, the orientation of the motor horns is critical to ensure proper movement and reliability. Refer to the reference images below to confirm correct positioning.

Refer to the schematics or the lamp base image above for proper wiring orientation and connection order.

> ⚠️ _Reminder:_ If your motor wire isn't long enough, you have to extend them through another wire by [splicing the wires](https://www.youtube.com/watch?v=r7GlDBge_WU).

### 3. Assembling the LeLamp Head

Connect the LED matrix in the head to the Raspberry Pi hat in the base. The image below shows the general wiring layout:

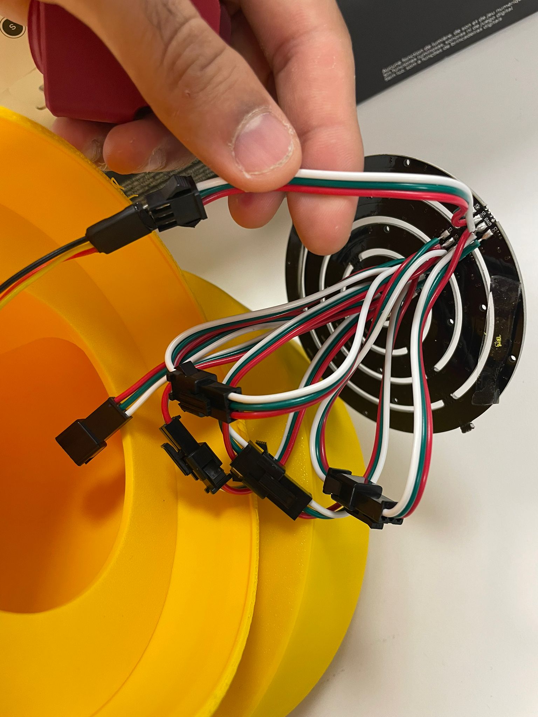
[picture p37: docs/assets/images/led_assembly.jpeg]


1. **Connect to the Pi hat:** Use a **female connector** that plugs into the Raspberry Pi hat's LED output pins.

2. **Route the wire:** Run the wire from the base all the way up to the head. You can solder good quality wire in between to extend the connection as needed. Ensure the wire is at least **50 cm** long to reach from the head to the base.

3. **Connect to the LED matrix:** The head comes with preset LED connectors. Simply plug your wire into these connectors as in the image above.

4. **Follow color conventions:**

   - **Black** — GND
   - **Red** — 5V
   - **Yellow** — Data

5. If you're unfamiliar with WS2812B LED wiring, refer to this [tutorial](https://lastminuteengineers.com/ws2812b-arduino-tutorial/).

6. The image above also indicates the **orientation and placement** of the LED matrix inside the head.
7. Finally, push the lamp shade cover (the one that goes in front of the LED) into the lamp shade.

## Power

You'll need 2 power supplies to power LeLamp:

1. **A 5V 2A DC Power Supply With DC Plug**: This is used to provide power to the servos.
2. **A 5V 2A Type C Charger**: This is used to provide power to the Rasperry Pi.

You can reduce the amount of power supply to 1 by providing the 5V from the motor driver to the pi. However, this is not recommended and has high risk of bricking your Pi.

## Assembly Completion Checklist

After completing lamp assembly, verify:

- [ ] All parts are connected
- [ ] An assembled LeLamp

## What You Should Have

At this stage, you should have:

- **Functional head assembly** with all electronics working
- **Proper cable management** with wires routed through head structure

---

**Previous**: [Servo Setup](./2.%20Servos%20Setup.md) | **Next**: [LeLamp Setup](./4.%20LeLamp%20Setup.md)

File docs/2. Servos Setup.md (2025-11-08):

# Servo Setup

**⏱️ Estimated time:** 30-45 minutes  
**🔧 Required tools:** Computer, servo driver, USB cable  
**📦 Required components:** 5x STS3215 servos, servo driver board

The first part of assembling LeLamp is setting up your servos.

## 0. Download LeLamp Runtime on your computer

On your personal computer, using the CLI terminal of your choice, clone the [LeLamp's Runtime Repository](https://github.com/humancomputerlab/lelamp_runtime):

```sh
git clone https://github.com/humancomputerlab/boxbots_lelampruntime/tree/Master
cd boxbots_lelampruntime
```
> If you are working on a 12V Lelamp kit then switch to the 12Vruntime branch on this repo. If you are running the 7.4V kit then remain on master.

```sh
git checkout 12Vruntime
```

Install uv:

```bash
curl -LsSf https://astral.sh/uv/install.sh | sh
```

Then setup the runtime by:

```bash
uv sync
```

In later part of this tutorial, you will have to setup LeLamp's runtime again, but on your Raspberry Pi.

## 1. Unbox and lay your servos on a table.

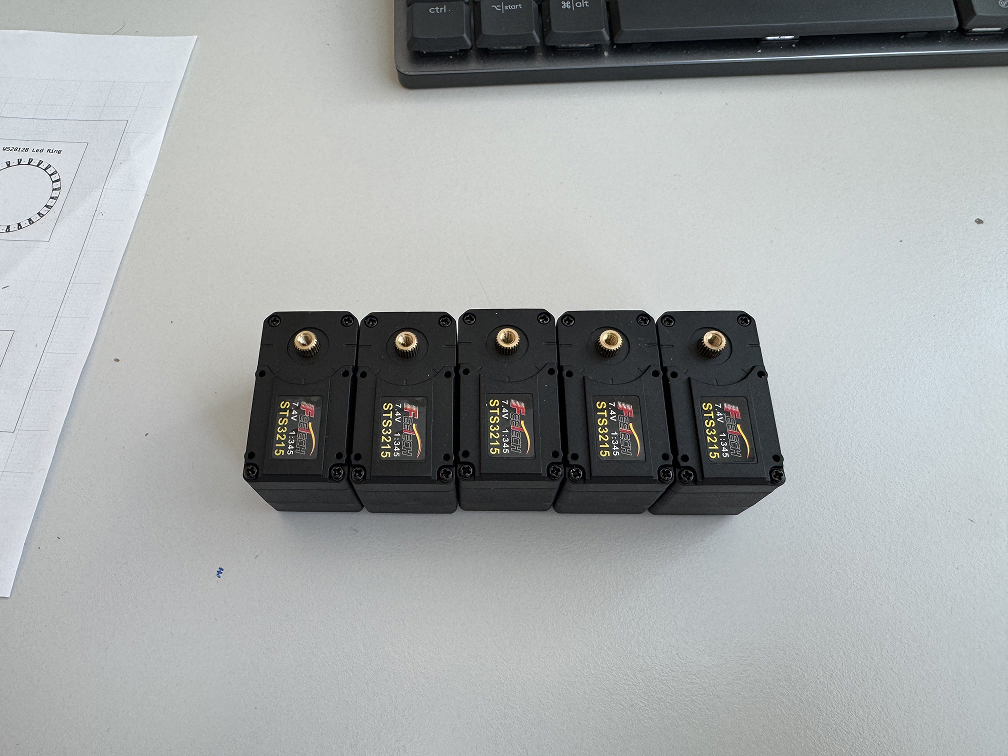
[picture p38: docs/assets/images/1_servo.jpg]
Servos on table


## 2. Label your servos.

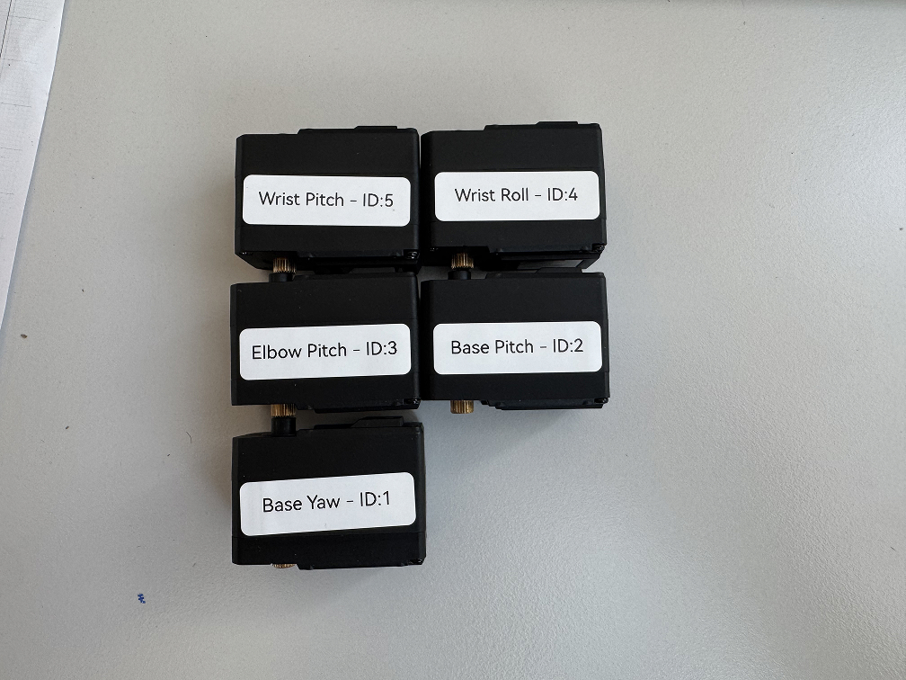
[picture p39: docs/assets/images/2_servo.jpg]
Label your servos.


| Servo Name  | Servo ID |
| --- | --- |
| base_yaw | 1 |
| base_pitch  | 2 |
| elbow_pitch | 3 |
| wrist_roll  | 4 |
| wrist_pitch | 5 |

Based on the table above, you should label your servo accordingly. There's no particular order to this or specific servo you should label with a certain ID.

The end result is having 5 servos, each with a label that tells you which is which.

## 3. Run LeLamp's motor setup script.

<!-- @CHRIS -->

> Note: If your motors were previously configured to use 5V then you will receive a voltage error when running through these steps. Notify us if that is the case.

<!-- - Connect 5V power, run motor setup. You will receive a voltage error.
- Then plug in the 12V Power and run the setup again. This time the motor ID will be set.
- The setup starts at ID 5. To setup the other IDs, keep the motor plugged in a press enter until it sets the correct ID -->

This step should be done on your personal computer or laptop.

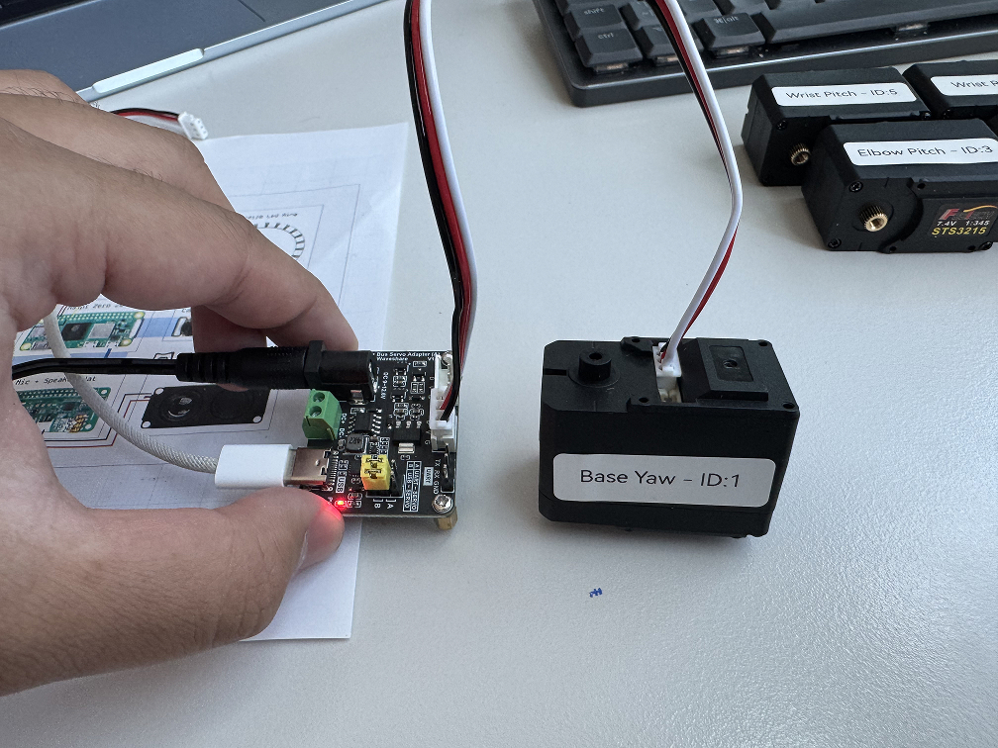
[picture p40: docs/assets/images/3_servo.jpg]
Run LeLamp's motor setup script


Connect the servo driver to your computer and figure which port it is connected to.

Inside `lelamp_runtime`, you can find port this by running:

```bash
uv run lerobot-find-port
```

Note: For motor setup and control, LeLamp Runtime can run on your computer and you only need to run uv sync. For other functionality that connects to the head Pi (LED control, audio, camera), you need to install LeLamp Runtime on that Pi and run uv sync --extra hardware.

If you have LFS problems, run the following command:

```bash
GIT_LFS_SKIP_SMUDGE=1 uv sync
```

For motor setup, inside `lelamp_runtime`, run the following command and connect the servo accordingly:

```bash
uv run -m lelamp.setup_motors --id your_lamp_name --port port_your_servo_driver_is_connected_to
```

Example:

```bash
uv run -m lelamp.setup_motors --id lelamp --port /dev/tty.usbmodem5A680114681
```

Remember the name you set for your lamp, you will use it again in the future.

## Success Criteria

After completing servo setup, you should have:

- [ ] 5 servos labeled with their intended positions
- [ ] All servos responding correctly to commands
- [ ] Servo IDs properly configured (1-5)
- [ ] Motor setup script completed successfully

## Troubleshooting

**Common issues:**

- **Servo not detected**: Check USB connection and port
- **Permission errors**: May need `sudo` or add user to dialout group
- **Servo ID conflicts**: Ensure each servo has unique ID

---

**Previous**: [3D Print](./1.%203D%20Print.md) | **Next**: [Lamp Assembly](./3.%20LeLamp%20Assembly.md.md)

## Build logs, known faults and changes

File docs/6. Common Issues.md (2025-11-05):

# LeLamp Troubleshooting Guide

This guide covers common issues encountered during LeLamp assembly and operation, with step-by-step solutions.

## 1. Hardware Issues

### RGB Problems

**Problem**: The LED matrix doesn't light up fully.

- **Edit number of LEDs**: You can edit the number of LED used in lelamp_runtime: `/lelamp/service/rgb/rgb_service.py`. You can find led_count as an default parameter of RGBService Class. Change this to change the number of LEDs or change the number in any instantiation of this class.

### Pi Setup Problems

**Problem**: Cannot SSH into Pi

- **Check network connection**: Verify Pi is connected to WiFi
- **Verify SSH enabled**: Ensure SSH was enabled during OS setup
- **Check hostname**: Try IP address instead of hostname.local
- **Firewall issues**: Temporarily disable computer firewall for testing

**Problem**: Runtime installation fails

- **Check internet connection**: Ensure Pi has stable internet access
- **Update system**: Run `sudo apt update && sudo apt upgrade` first
- **Install uv manually**: Follow official uv installation instructions
- **Check disk space**: Ensure sufficient space on SD card (16GB+ recommended)

**Problem**: Permission errors during testing

- **Use sudo for hardware tests**: RGB and some sensor tests require root access
- **Check user groups**: Add pi user to gpio, i2c, spi groups
- **Verify device permissions**: Check /dev/ device file permissions

## 2. Wi-Fi Issues

When your Raspberry Pi cannot connect to a known Wi-Fi network (e.g., you’ve moved locations or changed routers), there are several methods to reconfigure Wi-Fi access. Each method has tradeoffs depending on whether you still have SSH or physical access.

### Method 1: Use Ethernet (Or if you have SSH access)

If you can connect your Raspberry Pi to an Ethernet cable:

1. Plug the Pi into a router or computer via Ethernet.
2. Check the Pi’s IP address from your router’s device list or using a network scanner like `nmap`.
3. SSH into the Pi:

   ```bash
   ssh pi@<ethernet_ip_address>
   ```

4. Launch the configuration tool:

   ```bash
   sudo raspi-config
   ```

5. Navigate to:

   ```pgsql
   System Options → Wireless LAN
   ```

6. Enter your Wi-Fi SSID and password when prompted.
7. Reboot the Pi to apply changes:
   ```bash
   sudo reboot
   ```

This is the most reliable method since you keep full SSH access throughout.

If you can't edit using raspi-config:

1. Edit the Wi-Fi configuration file:

   ```bash
   sudo nano /etc/wpa_supplicant/wpa_supplicant.conf
   ```

2. Add or update your Wi-Fi network block:

   ```bash
   country=US
   ctrl_interface=DIR=/var/run/wpa_supplicant GROUP=netdev
   update_config=1

   network={
       ssid="YourNetworkName"
       psk="YourNetworkPassword"
   }
   ```

3. Save (Ctrl+O, Enter) and exit (Ctrl+X).

4. Reboot the Pi to apply changes:

```bash
sudo reboot
```

### Method 2: Share a Hotspot with the Same Name and Password

If you can’t physically reach the Pi or connect Ethernet:

1. Create a mobile hotspot on your phone or laptop.
2. Use **the exact same SSID (network name)** and **password** as your old Wi-Fi network.
3. The Raspberry Pi will automatically reconnect to this hotspot, since it matches its saved credentials.

> 💡 This method is great for quick recovery if you forgot to update the Wi-Fi credentials before moving the Pi.

### Method 3: SD Card Method (Unreliable)

If you can’t SSH in or use Ethernet:

1. Power off the Raspberry Pi and remove the SD card.
2. Insert it into another computer.
3. Open the **boot** partition (the only visible partition on most systems).
4. Create a new file named `wpa_supplicant.conf` in the boot directory with the following contents:

   ```bash
   country=US
   ctrl_interface=DIR=/var/run/wpa_supplicant GROUP=netdev
   update_config=1

   network={
       ssid="YourNetworkName"
       psk="YourNetworkPassword"
   }
   ```

5. Save the file using **UTF-8 encoding** and ensure there are **no extra spaces or smart quotes**.
6. Safely eject the SD card and reinsert it into the Pi.
7. Boot up — the Pi will copy this configuration into `/etc/wpa_supplicant/` automatically.

> **Note:**
>
> - This method is less reliable on some OS versions (especially Raspberry Pi OS Bookworm).
> - Incorrect country codes or malformed files can cause Wi-Fi to fail entirely.
> - Always ensure you use plain text and standard quotation marks.

## Getting Additional Help

### Before Asking for Help

1. **Check this troubleshooting guide** thoroughly
2. **Search existing GitHub issues** for similar problems
3. **Collect diagnostic information** using commands above
4. **Take clear photos** of your setup if hardware-related

### Where to Get Help

- **GitHub Issues**: https://github.com/humancomputerlab/le_lamp/issues
- **Discord Community**: https://discord.gg/4hmNW3Ep
- **LeLamp Runtime Issues**: https://github.com/humancomputerlab/lelamp_runtime/issues

### What Information to Include

- **Problem description**: Clear, specific description of the issue
- **Steps to reproduce**: Exact sequence that leads to the problem
- **Error messages**: Complete error text, not screenshots of text
- **System information**: Pi model, OS version, hardware configuration
- **Photos**: Clear images of your setup for hardware issues

## Component Testing Order

When diagnosing issues, test components in this order:

1. **Power supply**: Verify voltage and current capacity
2. **Individual servos**: Test each servo separately
3. **Servo driver**: Verify communication and control
4. **Pi connectivity**: Ensure SSH and basic operation
5. **Individual sensors**: Camera, microphone, speakers separately
6. **Integrated systems**: Full lamp operation

This systematic approach helps isolate problems and avoid cascading failures.

---

**Previous**: [LeLamp Control](./5.%20LeLamp%20Control.md)

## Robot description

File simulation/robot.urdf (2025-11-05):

<?xml version="1.0" ?>
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
<robot name="simulation">
  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
  <link name="lamparm__base_elbow">
    <inertial>
      <origin xyz="0.0729066 -0.0229022 0.217607" rpy="0 0 0"/>
      <mass value="0.234138"/>
      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
    </inertial>
    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
  </link>
  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
  <link name="lamparm__wrist_head">
    <inertial>
      <origin xyz="0.0193636 0.000541554 -0.0196637" rpy="0 0 0"/>
      <mass value="0.0953804"/>
      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
    </inertial>
    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
  </link>
  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
  <link name="scs215_v5">
    <inertial>
      <origin xyz="0.00584437 0.00206639 -0.0244202" rpy="0 0 0"/>
      <mass value="0.41735"/>
      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
    </inertial>
    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
  </link>
  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
  <link name="imu_site">
    <origin xyz="0 0 0" rpy="0 -0 0"/>
    <inertial>
      <origin xyz="0 0 0" rpy="0 0 0"/>
      <mass value="1e-9"/>
      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
    </inertial>
  </link>
  <joint name="imu_site_frame" type="fixed">
    <origin xyz="-3.4944e-17 4.02192e-17 -0.0378" rpy="3.14159 -5.41191e-15 1.87944"/>
    <parent link="scs215_v5"/>
    <child link="imu_site"/>
    <axis xyz="0 0 0"/>
  </joint>
  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
  <joint name="1" type="revolute">
    <origin xyz="0.04111 7.30741e-16 -0.0192" rpy="-1.5708 5.39003e-15 1.5708"/>
    <parent link="lamparm__wrist_head"/>
    <child link="scs215_v5"/>
    <axis xyz="0 0 1"/>
    <limit effort="10" velocity="10" lower="-5.02103" upper="1.26215"/>
  </joint>
  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
  <joint name="2" type="revolute">
    <origin xyz="0.00583234 0.0182927 0.08291" rpy="-1.26215 1.5708 0"/>
    <parent link="lamparm__base_elbow"/>
    <child link="lamparm__wrist_head"/>
    <axis xyz="0 0 1"/>
    <limit effort="10" velocity="10" lower="-1.08426" upper="2.05734"/>
  </joint>
  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
  <link name="lamparm__elbow_wrist">
    <inertial>
      <origin xyz="-0.00212937 0.119295 0.0220282" rpy="0 0 0"/>
      <mass value="0.206448"/>
      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
    </inertial>
    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
  </link>
  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
  <link name="lamparm__wrist_head_2">
    <inertial>
      <origin xyz="0.000541554 -0.000463734 -0.0217464" rpy="0 0 0"/>
      <mass value="0.0953804"/>
      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
    </inertial>
    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
  </link>
  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
  <link name="diffuser">
    <inertial>
      <origin xyz="-0.0641891 0.0560099 0.0186249" rpy="0 0 0"/>
      <mass value="0.0933113"/>
      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
    </inertial>
    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
  </link>
  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
  <joint name="5" type="revolute">
    <origin xyz="1.58207e-15 0.0192 -0.04111" rpy="1.5708 -1.5708 0"/>
    <parent link="lamparm__wrist_head_2"/>
    <child link="diffuser"/>
    <axis xyz="0 0 1"/>
    <limit effort="10" velocity="10" lower="-0.853337" upper="2.28826"/>
  </joint>
  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
  <joint name="4" type="revolute">
    <origin xyz="2.55351e-15 0.185185 0.006125" rpy="1.5708 -0.644947 2.92255e-15"/>
    <parent link="lamparm__elbow_wrist"/>
    <child link="lamparm__wrist_head_2"/>
    <axis xyz="0 0 1"/>
    <limit effort="10" velocity="10" lower="-3.78654" upper="2.49665"/>
  </joint>
  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
  <joint name="3" type="revolute">
    <origin xyz="0.105806 -0.0129789 0.301237" rpy="1.5708 -1.54809 -0.308645"/>
    <parent link="lamparm__base_elbow"/>
    <child link="lamparm__elbow_wrist"/>
    <axis xyz="0 0 1"/>
    <limit effort="10" velocity="10" lower="-2.82002" upper="0.321569"/>
  </joint>
  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
  <sensor>
    <accelerometer name="accel_sensor" site="imu_site"/>
    <gyro name="gyro_sensor" site="imu_site"/>
  </sensor>
  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
  <default>
    <default class="sts3215">
      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
      <joint damping="0.60" frictionloss="0.052" armature="0.028"/>
      <position kp="17.8" kv="0.0" forcerange="-3.35 3.35"/>
    </default>
    <default class="backlash">
      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
      <joint damping="0.01" frictionloss="0" armature="0.01" limited="true" range="-0.008726646259971648 0.008726646259971648"/>
    </default>
  </default>
</robot>

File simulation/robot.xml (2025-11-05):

<?xml version="1.0" ?>
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
<mujoco model="simulation">
  <compiler angle="radian" meshdir="assets" autolimits="true"/>
  <default>
    <default class="simulation">
      <joint frictionloss="0.1" armature="0.005"/>
      <position kp="50" dampratio="1"/>
      <default class="visual">
        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
      </default>
      <default class="collision">
        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
      </default>
    </default>
  </default>
  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
  <sensor>
    <accelerometer name="accel_sensor" site="imu_site"/>
    <gyro name="gyro_sensor" site="imu_site"/>
  </sensor>
  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
  <default>
    <default class="sts3215">
      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
      <joint damping="0.60" frictionloss="0.052" armature="0.028"/>
      <position kp="17.8" kv="0.0" forcerange="-3.35 3.35"/>
    </default>
    <default class="backlash">
      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
      <joint damping="0.01" frictionloss="0" armature="0.01" limited="true" range="-0.008726646259971648 0.008726646259971648"/>
    </default>
  </default>
  <worldbody>
    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
    <body name="lamparm__base_elbow" pos="0 0 0" quat="1 0 0 0" childclass="simulation">
      <freejoint name="lamparm__base_elbow_freejoint"/>
      <inertial pos="0.0729066 -0.0229022 0.217607" mass="0.234138" fullinertia="0.0010919 0.00129476 0.000320305 7.35843e-05 -0.000504692 0.000161616"/>
      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
      <body name="lamparm__wrist_head" pos="0.00583234 0.0182927 0.08291" quat="0.570913 -0.417203 0.570913 0.417203">
        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
        <joint axis="0 0 1" name="2" type="hinge" range="-1.0842575396713956 2.0573351139183975" class="sts3215"/>
        <inertial pos="0.0193636 0.000541554 -0.0196637" mass="0.0953804" fullinertia="1.16713e-05 2.19256e-05 1.7794e-05 -3.19269e-07 9.361e-07 6.98105e-08"/>
        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
        <body name="scs215_v5" pos="0.04111 7.30741e-16 -0.0192" quat="0.5 -0.5 -0.5 0.5">
          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
          <joint axis="0 0 1" name="1" type="hinge" range="-5.021033992714066 1.2621513144655205" class="sts3215"/>
          <inertial pos="0.00584437 0.00206639 -0.0244202" mass="0.41735" fullinertia="0.00100304 0.00122902 0.00205034 -8.49257e-05 -8.64397e-06 -3.34823e-06"/>
          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
        </body>
      </body>
      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
      <body name="lamparm__elbow_wrist" pos="0.105806 -0.0129789 0.301237" quat="0.575614 0.423658 -0.566139 0.410693">
        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
        <joint axis="0 0 1" name="3" type="hinge" range="-2.820024081304335 0.3215685722854582" class="sts3215"/>
        <inertial pos="-0.00212937 0.119295 0.0220282" mass="0.206448" fullinertia="0.000632713 4.80236e-05 0.000602863 -1.84707e-05 -1.72868e-06 -1.49987e-05"/>
        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
        <body name="lamparm__wrist_head_2" pos="2.55351e-15 0.185185 0.006125" quat="0.670659 0.670659 -0.224092 0.224092">
          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
          <joint axis="0 0 1" name="4" type="hinge" range="-3.7865399953934267 2.4966453117861596" class="sts3215"/>
          <inertial pos="0.000541554 -0.000463734 -0.0217464" mass="0.0953804" fullinertia="2.19256e-05 1.7794e-05 1.16713e-05 6.98105e-08 -3.19269e-07 9.361e-07"/>
          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
          <body name="diffuser" pos="1.58207e-15 0.0192 -0.04111" quat="0.5 0.5 -0.5 0.5">
            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
            <joint axis="0 0 1" name="5" type="hinge" range="-0.8533371981959901 2.288255455393803" class="sts3215"/>
            <inertial pos="-0.0641891 0.0560099 0.0186249" mass="0.0933113" fullinertia="0.000164418 0.000170062 0.000206169 2.06383e-05 7.21792e-11 4.01082e-10"/>
            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
          </body>
        </body>
      </body>
    </body>
  </worldbody>
  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
  <actuator>
    <position class="sts3215" name="2" joint="2" inheritrange="1"/>
    <position class="sts3215" name="1" joint="1" inheritrange="1"/>
    <position class="sts3215" name="3" joint="3" inheritrange="1"/>
    <position class="sts3215" name="4" joint="4" inheritrange="1"/>
    <position class="sts3215" name="5" joint="5" inheritrange="1"/>
  </actuator>
  <equality/>
</mujoco>

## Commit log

2025-11-06 📝 update start of docs with WIP for chris
2025-11-06 🐛 new image
2025-11-06 📝 add screws info
2025-11-07 Update 3. LeLamp Assembly.md
2025-11-07 add base mount images and text
2025-11-07 updating schematics
2025-11-07 Revise LED wiring instructions in LeLamp Assembly guide
    Updated assembly instructions for LeLamp, including details on wiring and connections for LEDs and speakers.
2025-11-07 Update OnShape assembly link for LeLamp Body
2025-11-07 servo setup updates
2025-11-08 CAD files updated
    [LampArm (Base-Elbow).3mf, LampArm (Elbow-Wrist).3mf, LampArm (Pitch).3mf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]
2025-11-08 updated soldering hat
2025-11-08 📝 add lamp body assembly
2025-11-08 📝 add workflow documentation
2025-11-08 📝 mobile hotspot reminder
